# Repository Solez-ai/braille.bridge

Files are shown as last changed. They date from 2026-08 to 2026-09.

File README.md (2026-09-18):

# BrailleBridge

*A low-cost, bilingual (English + Bangla) digital Braille writing and classroom examination system.*

BrailleBridge lets blind and visually impaired students write independently — during classwork, assignments, and formal examinations — using familiar six-dot Braille chords. An ESP32 translates each chord in real time into readable English, Bangla, numbers, punctuation, and mathematical symbols, and delivers the result over two independent channels:

- **Bluetooth HID keyboard** — the output appears on the student's own phone, tablet, or computer, where a built-in screen reader reads it aloud.
- **USB Serial** — the same text arrives in the browser-based **Teacher Software**, giving sighted teachers readable output without ever learning Braille.

---

## Table of Contents

- [Why BrailleBridge](#why-braillebridge)
- [Key Features](#key-features)
- [Repository Structure](#repository-structure)
- [Hardware](#hardware)
  - [Bill of Materials](#bill-of-materials)
  - [GPIO Mapping](#gpio-mapping)
- [How It Works](#how-it-works)
  - [Braille Chording](#braille-chording)
  - [Language Switching](#language-switching)
  - [Shift Modifier](#shift-modifier)
- [Getting Started](#getting-started)
  - [Firmware (ESP32)](#firmware-esp32)
  - [Teacher Software](#teacher-software)
  - [Marketing Website](#marketing-website)
  - [3D-Printed Enclosure](#3d-printed-enclosure)
- [Serial Protocol](#serial-protocol)
- [Documentation](#documentation)
- [Roadmap](#roadmap)
- [License](#license)
- [Author](#author)

---

## Why BrailleBridge

In many classrooms and examination halls, a blind student cannot independently produce an answer sheet that a sighted teacher can immediately read. The common workaround — dictating every answer to a sighted writer — forces the student to:

- Speak answers aloud, losing privacy and confidentiality;
- Work at the writer's pace, losing control over speed;
- Risk transcription errors in technical terms, names, and Bangla phonetics;
- Hand over control of the final written record entirely.

Traditional embossed Braille solves the writing problem but is unreadable to most sighted teachers, and commercial digital Braille systems can cost hundreds or thousands of dollars.

BrailleBridge addresses the whole gap: the student writes through familiar Braille chords, the ESP32 translates instantly, and the teacher receives ordinary digital text — at a bill-of-materials cost of roughly **$12 per device**.

---

## Key Features

**Hardware device**

- Six mechanical Braille dot keys (Outemu Red, rated ~50M presses) plus dedicated Space and Shift keys
- ESP32 Dev Module with Bluetooth and USB Serial
- 180 ms chording window that reliably merges near-simultaneous key presses
- Two status LEDs (Red = English, Green = Bangla)
- Custom 3D-printed enclosure (Fusion 360 / FDM, top and bottom shells)
- Software language switching — no physical toggle switch required

**Translation**

- Full English alphabet (Grade 1 Braille, A–Z)
- Full Bangla dictionary following the **Bharati Braille** standard (vowels, consonants grouped by varga, vowel signs, halant, anusvara, visarga, candrabindu)
- Shift layer for numbers (1–0), punctuation, and math symbols (`+ - × ÷ =`)
- Shift + vowel produces Bangla dependent vowel signs (kar/matra)
- Unknown chords are rejected cleanly with LED blink feedback

**Teacher Software (browser-based)**

- Zero installation — runs in Chrome/Edge via the Web Serial API
- Multi-student roster with per-student COM ports and baud rates
- Live real-time feeds with language detection (`LANG:en` / `LANG:bn`)
- Exam mode: all students side by side in a monitoring grid
- Expandable per-student view with large serif text
- Timestamped exports (`[HH:MM:SS]` per character) as `.txt` files
- Persistent roster via `localStorage`
- Light/dark theme with `Ctrl+Shift+T` shortcut

---

## Repository Structure

```
.
├── braile/
│   └── braile.ino            # ESP32 firmware (Arduino / C++)
├── braille-display/
│   ├── index.html            # Teacher Software
│   ├── script.js
│   └── style.css
├── website/
│   ├── index.html            # Marketing / project website
│   ├── script.js
│   └── style.css
├── docs/
│   ├── braillebridge.tex     # Full research paper (XeLaTeX / LuaLaTeX)
│   └── ppt.pptx              # Presentation materials
├── models/
│   ├── TOP_SHELL.stl         # 3D-printable enclosure top
│   └── BOTTOM_SHELL.stl      # 3D-printable enclosure bottom
├── LICENSE                   # Apache License 2.0
└── README.md
```

---

## Hardware

### Bill of Materials

| Component | Qty | Cost (USD) |
| --- | --- | --- |
| ESP32 Dev Module | 1 | $5.00 |
| Outemu Red switch | 8 | $3.00 |
| Keycaps (3D-printed) | 8 | $1.00 |
| LED (3mm) + resistor | 2+2 | $0.30 |
| Perfboard | 1 | $0.80 |
| PLA filament (enclosure) | 30g | $1.20 |
| M3 screws, wire, solder  | — | $0.70 |
| **Total** | | **~$12.00**|

### GPIO Mapping

| Function | ESP32 GPIO | Notes |
| --- | --- | --- |
| Dot 1 | 14 | Top-left |
| Dot 2 | 12 | Middle-left |
| Dot 3 | 13 | Bottom-left |
| Dot 4 | 27 | Top-right |
| Dot 5 | 26 | Middle-right |
| Dot 6 | 25 | Bottom-right |
| Space | 33 | Dedicated space |
| Shift | 32 | Modifier |
| Red LED  | 18 | English mode |
| Green LED| 19 | Bangla mode |

All switches share a common ground bus. The firmware uses the ESP32's internal pull-up resistors: unpressed reads `HIGH`, pressed reads `LOW`.

---

## How It Works

### Braille Chording

A six-dot Braille cell is laid out as:

```
1 4
2 5
3 6
```

A character is produced by pressing one or more dots simultaneously. Each dot maps to a bit in a 6-bit value:

| Dot | Bit |
| --- | --- |
| 1 | 0 |
| 2 | 1 |
| 3 | 2 |
| 4 | 3 |
| 5 | 4 |
| 6 | 5 |

Because human fingers rarely land at the exact same microsecond, the firmware collects all keys pressed within a **180 ms window**, ORs them into a single chord value, and looks up the result in the active language dictionary.

Example: dots 1 + 4 → `0b001001` → **c** (English) / **চ** (Bangla).

### Language Switching

Hold **dots 4 + 5 + 6 for 500 ms** to toggle between English and Bangla. This exact chord is used by no standard letter or symbol, so accidental switching is practically impossible. The LEDs confirm the active language, and the firmware announces the change over Serial (`LANG:en` / `LANG:bn`) so the Teacher Software can update its indicator.

### Shift Modifier

Holding the physical Shift key while pressing a chord expands the vocabulary:

| Shift + chord | Output |
| --- | --- |
| Shift + A–J | Numbers 1–0 |
| Shift + math chord | `+`, `-`, `×`, `÷`, `=` |
| Shift + punctuation| `,` `;` `:` `.` |
| Shift + letter (EN)| Uppercase letter |
| Shift + vowel (BN) | Bangla vowel sign (kar/matra) |

### Shift Tap = Backspace

Tapping Shift alone (press + release **without** composing any chord) deletes the last typed character, like a normal keyboard's Backspace. All the hold-to-modify combos above work exactly as before — only a clean, unused tap fires the delete.

Guards so it never misfires:

- **Dots down during the tap** → modifier mode, no delete (checked both when dots are pressed and when Shift is released mid-chord).
- **Press shorter than 25 ms** → treated as bounce, ignored.
- **Hold longer than 1.5 s** → ignored, so pocketing the device can't wipe text.
- **100 ms cooldown** after a fired delete so contact bounce can't chain multiple backspaces.

The deletion goes out on both outputs: a real HID backspace over Bluetooth (works in any app on the connected computer/phone), and a `SYSTEM:BKSP` control line over Serial, which the Teacher Software already handles in student view, teacher mode, and exam mode.

### Shift Tap = Backspace

Tapping Shift alone (press + release **without** composing any chord) acts as a **Backspace** — it deletes the last typed character. Tap-and-chord combos behave exactly as before; only a clean, unused tap fires the delete. Deliberately long presses (>1.5 s) are ignored so the key can't misfire when pocketed.

The deletion is sent over both outputs: a real HID backspace to the connected device over Bluetooth, and a `SYSTEM:BKSP` control line over Serial, which the Teacher Software handles in student view, teacher mode, and exam mode.

---

## Getting Started

### Firmware (ESP32)

1. Install the [Arduino IDE](https://www.arduino.cc/en/software) and the [Arduino core for ESP32](https://github.com/espressif/arduino-esp32).
2. Open `braile/braile.ino` and upload it to an ESP32 Dev Module. *(No external libraries needed — the sketch uses only the ESP32 core's built-in BLE stack.)*
3. Pair the device (it appears as a Bluetooth keyboard named **BrailleBridge**) with the student's phone, tablet, or computer.
4. Open a text field, type Braille chords, and the translated text appears — while the same characters stream over USB Serial **and over BLE** to the Teacher Software.

> **BLE stream (Nordic UART Service):** alongside the HID keyboard service, the firmware now exposes the standard NUS (`6E400001-B5A3-F393-E0A9-E50E24DCCA9E`) — TX `…0002` notifies the exact serial stream (characters, `LANG:*`, `SYSTEM:BKSP`), RX `…0003` accepts `LANG:en` / `LANG:bn` commands back. This is the channel the future phone app (see [PHONE.md](PHONE.md)) consumes — no USB cable required.
>
> **Firmware v4 — BLE layer restored to the proven library:** after the v2/v3 hand-rolled GATT rewrites broke typing (malformed report-map Report-ID item) and then discoverability (advertising payload overflow), the BLE layer is back on the **T-vK BleKeyboard code that worked in v1** — vendored directly into the sketch folder as `braile/BBKeyboard.h/.cpp`, so no library install is needed. The **Nordic UART Service is grafted onto that proven stack** (own service UUID, doesn't touch HID/pairing/advertising), giving the phone app its data stream. Reflash once: phone keyboard mode, PC typing, and the app stream all come back together.

### Teacher Software

1. Open `braille-display/index.html` in **Chrome** or **Edge** (both support the Web Serial API).
2. Connect the ESP32 via USB; the browser will prompt you to select the serial port (115200 baud).
3. Add students, assign each to a COM port, and watch their typing appear live.
4. Use **Exam Mode** to monitor the whole class side by side, and **Export** to save timestamped logs per student.

No server, no database, and no installation required — the browser talks directly to the devices.

### Marketing Website

Open `website/index.html` in any browser, or deploy the folder to any static host (GitHub Pages, Netlify, etc.) for a public project site.

### 3D-Printed Enclosure

Print `models/TOP_SHELL.stl` and `models/BOTTOM_SHELL.stl` on an FDM printer (PLA, 0.2 mm layers). The MX-compatible switch cutouts let the eight Outemu switches snap in without glue or solder; the two shells fasten together with M3 screws.

---

## Serial Protocol

All translation happens on the ESP32, so the serial line carries only results at **115200 baud** (and the identical byte stream is mirrored over the BLE Nordic UART Service for the phone app):

| Message | Meaning |
| --- | --- |
| `LANG:en` | Language switched to English |
| `LANG:bn` | Language switched to Bangla |
| `Invalid` | Unrecognised chord rejected |
| `SYSTEM:BKSP` | Shift tap → delete last character |
| `<char>` | A translated character |

---

## Documentation

A full research paper is included at `docs/braillebridge.tex`. It covers the problem statement, hardware and firmware architecture, the English and Bharati Bangla dictionaries, the Teacher Software design, comparative analysis, affordability, and engineering innovations.

Compile it with **XeLaTeX or LuaLaTeX** (required for full Unicode/Bangla support):

```bash
xelatex braillebridge.tex
```

---

## Roadmap

- Verified full Bharati Braille implementation with experienced users
- Full mathematical Braille code (fractions, brackets, powers)
- Battery power with USB-C charging and battery reporting
- Audio confirmation and vibration feedback
- Secure examination mode with student identification
- PDF/DOCX export and cloud synchronisation
- Multi-school deployment and remote grading

---

## License

Licensed under the **Apache License, Version 2.0**. See [LICENSE](LICENSE) for the full text.

---

## Author

**Samin Yeasar**

- Email: [samin@mentormind.bd](mailto:samin@mentormind.bd)
- GitHub: [github.com/Solez-ai](https://github.com/Solez-ai)
- Web: [solez.html-5.me](https://solez.html-5.me)

*BrailleBridge does not replace Braille. It protects Braille as the student's natural writing method while removing the barrier between Braille input and teacher-readable output.*

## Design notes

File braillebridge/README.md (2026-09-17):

# BrailleBridge — Android App (Kotlin / Compose)

The mobile counterpart to the ESP32 BrailleBridge keyboard: receives the live
character + control-line stream over **Bluetooth Low Energy** (Nordic UART
Service) and mirrors every feature of the desktop/web teacher platform.

## ⚠️ How this app is built — READ FIRST

**Never build this app locally. No `gradlew`, no Android Studio builds on your
machine.** The single source of APKs is **GitHub Actions**:

1. Commit & push to `main` (any change — the workflow runs on every push).
2. Open the repo → **Actions** tab → *Build BrailleBridge APK*.
3. When the run finishes (green ✓), open it → **Artifacts** →
   **BrailleBridge-debug-apk** → download & unzip.
4. Copy `app-debug.apk` to your phone and install it
   (allow *Install unknown apps* for your file manager when prompted).

Need a build without a code change? **Actions → Build BrailleBridge APK →
Run workflow** (manual trigger).

The workflow (`.github/workflows/build-apk.yml`) uses JDK 17 + Gradle 9.3.1
and generates the debug keystore itself, so nothing secret is needed for
debug builds.

## Connecting to the BrailleBridge device

- **Keyboard mode (type into WhatsApp, any text field):** pair once in
  **Android Settings → Bluetooth** — the phone's own BLE HID stack handles it.
  No app involvement required.
- **App mode (live stream in this app):** open the app → the BLE service
  auto-connects to any device named *BrailleBridge* (or tap the Bluetooth
  icon in the top bar to scan manually).
- Both work at the same time: HID gives raw ASCII typing, the Nordic UART
  stream carries ASCII + Bangla + control lines (`LANG:*`, `SYSTEM:BKSP`).
- If characters ever stop appearing in the app: toggle the device's language
  switch (D4+D5+D6) — any `LANG:` line confirms the stream; if still silent,
  forget & re-pair the device in system settings, then reconnect.

## Feature parity

Student / Teacher / Exam / Exports tabs, teacher account (Samin Yeasar),
Google Translate with the full ~128-language catalogue, auto-formatted
export review with .txt download — all mirroring `braille-display/` and
`braille-desktop/`. Protocol and firmware details live in `PHONE.md`.

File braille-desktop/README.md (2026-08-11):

# BrailleBridge — Teacher Desktop

The BrailleBridge web app, wrapped in a desktop window with a **Python serial
relay**. Python owns every ESP32 COM port, so one device can be watched by the
Student View, the Teacher roster, and the Exam grid at the same time — no more
"Failed to open serial port" from two views fighting over one connection.

## Quick start

```bash
cd braille-desktop
pip install -r requirements.txt
python main.py
```

## What the Python side does

| Feature | Where |
|---|---|
| Owns COM ports (pyserial), one reader thread per port | `relay.py` |
| Streams every serial line/char into the embedded web UI | `relay.py` → `main.py` → JS |
| Auto-detects plug/unplug, pushes the port list to the UI | `relay.py` monitor loop |
| Auto-reconnects a dropped device when the port returns | `relay.py` monitor loop |
| Persists student ⇄ COM port assignments | `data/assignments.json` |
| Auto-saves each session as readable prose | `logs/` (on disconnect, Save Logs button, and app close) |

## Notes

- The window is Edge WebView2 (bundled with Windows 10/11). The browser
  version of `braille-display` still works unchanged — the app only switches
  to the relay transport when it detects `window.pywebview`.
- Google Fonts need an internet connection; offline the UI falls back to
  system serif fonts.
- Session logs land in `braille-desktop/logs/` as
  `{StudentName}_{timestamp}.log` with per-line timestamps.

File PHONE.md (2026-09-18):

# PHONE.md — Building BrailleBridge for Android (Kotlin, Bluetooth-Only)

> **Goal:** a phone app that looks and behaves **exactly** like the existing
> BrailleBridge teacher platform (`braille-display/` + `braille-desktop/`),
> except the transport is **Bluetooth Low Energy instead of USB serial** —
> with a **custom BLE proxy service that starts with the app**, so the phone
> takes full advantage of BLE from the first second.
>
> Every protocol rule, control line, boot-filter, chord table, timing constant
> and UI behavior below is copied **verbatim** from the current codebase, so
> the phone app is a drop-in replacement for the desktop one. Nothing about
> the student experience changes.

---

## 0. What must be identical (the rules)

| Rule | Value (do not change) | Source of truth |
|---|---|---|
| Device BLE name | `BrailleBridge` | `braile/braile.ino` — `BBKeyboard bleKeyboard("BrailleBridge")` (vendored T-vK library + NUS) |
| Serial baud (legacy/USB) | 115200 (also 9600/57600/38400 selectable) | `braille-display` UI + `braille-desktop/main.py` |
| Chord collection window | **180 ms** timeout, process on all-released OR timeout | `loop()` in `braile.ino` |
| Language toggle chord | Dots **4+5+6 held 500 ms** → toggle EN/BN, wait for release, then 50 ms settle | `loop()` |
| Shift behavior | Held = modifier; **tap alone (press+release, no chord) = BACKSPACE** | `braile.ino` shift state machine |
| Shift tap guards | min 25 ms, max 1500 ms, 100 ms cooldown, dots-held veto | `braile.ino` |
| Space | Immediate char + 200 ms debounce, block until released | `loop()` |
| Control lines | `SYSTEM:…`, `LANG:en`, `LANG:bn`, `Invalid`, `SHIFT` — never rendered as text | `relay.py CONTROL_PREFIXES` |
| Backspace control line | `SYSTEM:BKSP` on its own line | `sendBackspace()` |
| Language lines | `LANG:en` / `LANG:bn` (exactly, lowercase suffix) | `loop()` |
| Boot preamble filter | Drop `ets `, `rst:0x`, `boot:0x`, `configSPIWP`, `clk_drv:`, `q_drv:`, `d_drv:`, `cs0_drv:`, `hd_drv:`, `wp_drv:`, `mode:DIO`, `load:0x`, `entry 0x`; stateful: after `ets ` suppress until `entry 0x` or a `SYSTEM:` line | `relay.py BOOT_PREFIXES` + `makeBootFilter()` in `script.js` |
| Chord dictionaries | Bharati Braille tables — EN a–z, BN full varnmala, কার shift map, numbers 1–0 on Shift+A–J, math/punct symbols | `brailleDict[]`, `numberChords[]`, `shiftSymbols[]`, `banglaShiftMap[]` |
| Unknown chord | **Silently ignored** (no output, no error) | `processChord()` |
| BLE ASCII rule | Only ASCII goes to BLE HID; Bangla (multi-byte UTF-8) is serial/transport only — pushing it to HID wedges the ESP32 | `sendChar()` comment in `braile.ino` |

---

## 1. Transport: what changes on the phone

The desktop app reads the ESP32 over **USB COM port via pyserial**. On Android
there is no COM port — the same byte stream arrives over **BLE GATT
notifications**. The protocol layer above it must not change.

### 1.1 The ESP32 side — ✅ IMPLEMENTED (`braile/braile.ino`)

The firmware runs the **T-vK BleKeyboard code that worked in v1 — vendored
into the sketch folder** as `braile/BBKeyboard.h/.cpp` (class renamed
`BBKeyboard`), with the **Nordic UART Service grafted on** as a second
service. No library install needed. This is the proven pairing/typing stack
(keyboard appearance 0x03C1, SC+MITM bonding, T-vK report map and
advertising shape) plus one added data channel:

1. **HID over GATT (0x1812):** byte-for-byte the library build — paired
   hosts see a keyboard named **BrailleBridge** and receive ASCII typing
   exactly as v1 did on phones and PCs.
2. **Nordic UART Service (the proxy channel):** the *raw character +
   control-line stream* that goes to Serial is mirrored over BLE:

```cpp
// implemented — BBKeyboard.h (NUS ADDITION section)
#define NUS_SERVICE_UUID "6E400001-B5A3-F393-E0A9-E50E24DCCA9E"
#define NUS_TX_UUID      "6E400002-…"   // notify: chars, LANG:*, SYSTEM:BKSP
#define NUS_RX_UUID      "6E400003-…"   // write: phone can send LANG:en/LANG:bn
```

`sendChar()` writes to Serial **and** notifies NUS (MTU-chunked);
`streamLine()` does the same with `\n` appended. Non-subscribed centrals are
skipped automatically by the stack's CCCD handling.

**MTU:** the peripheral sets MTU 247. On the Android side call
`requestMtu(247)` right after `onDescriptorWrite` succeeds and **buffer
partial notifications** (see §2.3).

### 1.2 The BLE proxy service (starts with the app)

A foreground `Service` that owns *all* Bluetooth work, starts on app launch,
survives Activity recreation, and re-publishes itself:

```kotlin
class BleProxyService : Service() {
    // One connection per student device, mirroring relay.py's _conns map
    private val connections = ConcurrentHashMap<String, BleDeviceConn>()
    private val assignments = ... // persisted name->MAC, like data/assignments.json

    override fun onStartCommand(...) = START_STICKY
}
```

Responsibilities (each one maps 1:1 to `relay.py`):

| relay.py | BleProxyService |
|---|---|
| `_monitor_loop()` re-scan every 2 s | `ScanCallback` loop with `ScanSettings.SCAN_MODE_LOW_POWER` between windows; auto-connect by MAC when a **bonded/known** `BrailleBridge` device appears |
| `open_port(name, baud)` | `connectGatt(context, false, callback, TRANSPORT_LE)` + discovery + enable notifications |
| `close_port(name)` | `gatt.disconnect(); gatt.close()`, keep the conn object for reconnect |
| auto-reconnect on drop | `onConnectionStateChange → DISCONNECTED` ⇒ exponential backoff reconnect (1s, 2s, 4s… cap 10s), emit `reconnect` event when back |
| `_read_loop` incremental UTF-8 decoder | accumulate `ByteArray` notifications; decode with `CharsetDecoder` in `CodingErrorAction.REPLACE` — a Bangla char split across two notifications must not become garbage |
| `CONTROL_PREFIXES` routing | identical line splitter, §2.2 |
| logs/ + data/assignments.json | Room DB + DataStore, same JSON shape |

**Foreground requirement:** `FOREGROUND_SERVICE` + `BLUETOOTH_CONNECT` +
`ACCESS_FINE_LOCATION` (scan) permissions; show a persistent
"BrailleBridge BLE bridge active — N devices" notification. Start the service
in `Application.onCreate()` so BLE is live before the first frame renders —
that is the "proxy comes up as the app starts" rule.

### 1.3 Connection UX parity

- Student view "Connect" button lists nearby `BrailleBridge` devices
  (name-filtered scan), shows RSSI; remembers last device and auto-connects.
- Teacher roster Add-Student form: same three rows (Name / **Bluetooth**
  / "baud" row becomes **Device picker**) — keep the baud select in the UI for
  parity but disable it when connType = bluetooth (baud is a USB concept).
- Status dot + `Connected/Disconnected` label behave identically
  (`updateSerialUI` equivalent).

---

## 2. Protocol layer (port these exactly)

### 2.1 Line model

`makeSerialFeed(onLine, onChars)` in `script.js` is the canonical behavior:

```
buffer += chunk
while newline in buffer: emit trimmed line to onLine
if trailing partial: emit to onChars   // chars arrive without \n
```

The Kotlin port (`LineFeed`) must do the same split, then classify:

- starts with `SYSTEM:` → control (handle `SYSTEM:BKSP`, ignore rest)
- equals `LANG:en` / `LANG:bn` → switch language state, update indicators
- equals `Invalid` or `SHIFT` → ignore (never render)
- else → character data

### 2.2 Boot suppression (stateful port)

```
var suppress = false
fun dropLine(line): Boolean {
  if (line.startsWith("ets ")) { suppress = true; return true }
  if (suppress) {
    if (line.startsWith("entry 0x") || line.startsWith("SYSTEM:")) suppress = false
    else return true
  }
  return BOOT_PREFIXES.any(line::startsWith)
}
```
Partial chunks (`ets ` without newline) set suppress exactly like
`relay.py _read_loop`.

### 2.3 MTU-safe reassembly

BLE notifications arrive in ≤ (MTU-3) byte chunks. Reassemble at the byte
level, decode incrementally (surrogate-safe), then feed `LineFeed`. This
mirrors `codecs.getincrementaldecoder('utf-8')(errors='replace')`.

---

## 3. Dictionaries (port these tables byte-for-byte)

Copy from `braille-display/script.js` (identical to the firmware tables):

- `brailleDict` — 52 entries: shared EN/BN chords + Bangla-only cells +
  convenience cells (ি, ূ, duplicate স). Keep **`f`, `w` having `bangla: null`**
  and the `null` entries exactly — the "chord exists but not in this language"
  rule returns null (silently ignored).
- `numberChords` / `numberMap` — Shift+A–J → 1–0.
- `shiftSymbols` — math first (`+ − × ÷ =` — note `×` at 0b100110 shares chord
  with `,` handling order), then `, ; : .` (order matters: 0b010110 `+` before
  0b100110 `×`).
- `banglaShiftMap` — vowel → কার, with অ (0b000001) mapping to **null**
  → falls through to normal output (do not "fix" this).
- Translation priority when Shift held: numbers → math/punct → uppercase EN →
  কার BN → fallback normal BN char → else ignore.

## 4. Feature parity checklist (all of these exist today; all must exist on phone)

### Student view
- 6-dot clickable Braille cell with dot order layout (1-4 / 2-5 / 3-6 columns),
  pressed-dot animation + pulse, chord binary + dots readout, live mapping line
- English/বাংলা + Shift indicators (LED semantics: EN=red LED, BN=green LED)
- Live output stream with per-char spans, Bangla font stack
  (`Noto Serif Bengali → Nirmala UI → Vrinda`), blinking cursor, auto-scroll
- Recent characters strip (80-char rolling window)
- Clear button, keyboard shortcuts (1–6 dots, Space, Enter commit, Esc clear,
  L language, S shift) — on phone these become physical-keyboard support only
- **Backspace tap** reflected live (device Shift tap removes last char)
- Send-to-Teacher mirror (`mirrorStudentId` semantics: one connection, two views)

### Teacher view
- Roster with avatars (initials + 8-color palette `#5a8ae0 #d45a5a #5ab85a
  #c49a4a #8a6ad4 #4ac8b8 #e08a5a #5ab8b8`), online/offline dot, connect button
- Feed grid cards: header (avatar/name/conn badge/baud/status), body
  (live stream), chord bar (6 mini dots + `0b…` + char count)
- Per-card actions: Preview(prose) · Expand · Test(simulate `hello বাংলা`
  typing at 200 ms/char) · Export · Clear · Remove
- Toolbar: student count, total chars, Save Logs, **Export All**, Clear All
- Backspace handling per student (`handleStudentBackspace` pops `{char,time}`)
- Periodic 500 ms failsafe refresh of all feeds

### Exam view
- Same cards, no per-card actions, toolbar shows student/char counts,
  Export button — feeds stay live during exams, chars still timestamped

### Modals
- **Preview modal:** readable prose — group chars into words/lines, ≤52 chars
  per line after the `[HH:MM:SS]` prefix, line timestamp = first char typed;
  Export + Save-to-Exports buttons; footer "N character(s) — M line(s)"
- **Expand modal:** full live view of one student, scroll-to-bottom button,
  Ctrl+Enter clear, preview hand-off
- **Send modal:** mirror flow (name + conn + baud), duplicate-mirror guard

### Everything new that must also exist on phone (§6–§8)
- Teacher account UI — **Samin Yeasar** (identical to §7)
- Google Translate integration (identical to §6)
- Exports tab with saved exports, review screen, auto-formatter (§8)

---

## 5. Android architecture

```
/app
  /ble            BleProxyService, BleDeviceConn, GattCallbacks, LineFeed,
                  BootFilter, Utf8Reassembler      ← §1–2
  /protocol       BrailleDict.kt, Translate.kt (tables + lookup priority) ← §3
  /data           StudentRepo (Room: students, chars{char,time}, exports),
                  SettingsStore (theme, assignments JSON)
  /ui
    /student      StudentScreen (cell, output, translate bar)
    /teacher      RosterScreen, FeedGrid, StudentCard
    /exam         ExamScreen
    /exports      ExportsScreen (list) + ReviewScreen (formatted doc)
    /account      AccountSheet (Samin Yeasar profile)
    /theme        Theme.kt — port BOTH light & dark palettes
```

- **Jetpack Compose**, MVVM, one `SharedViewModel` per mode mirroring the
  global-state style of `script.js` (`students[]`, `totalCharsAllStudents`,
  `isBangla`, `shiftActive`).
- **Compose Multiplatform note:** not needed — single Android target.
- ViewModels survive rotation; the BLE service is the source of truth and
  pushes via `StateFlow` — exactly how `relay.py` pushes into the webview.

### Theme ports

Dark (default) from `style.css :root`:
`--bg-dark #0f111a · --bg-panel #161822 · --bg-card #1c1f2e ·
--bg-surface #242738 · --bg-hover #2d3044 · --text #e8e6e0 / #a8a4a0 / #6a6a7a ·
--gold #c49a4a · --gold-light #dbb86a · --gold-dark #a07828 ·
--accent-red #d45a5a · --accent-green #5ab85a · --accent-blue #5a8ae0 ·
--accent-purple #8a6ad4 · --accent-teal #4ac8b8 ·
--radius 8/14/20 · Inter + Playfair Display + Noto Serif Bengali`

Light: `#f4f3f0 / #ffffff / #faf9f6 / #efede8 / #e6e3dc`, ink `#1a1a2e`,
same accents. Ctrl+Shift+T theme toggle → app setting + top-bar icon.
The dot buttons use `linear-gradient(145deg …)` with the `0 5px 0` hard
drop-shadow — replicate with two-layer shadow in Compose.

---

## 6. Google Translate (same behavior on both platforms)

Reference implementation: `braille-display/shared.js → BBTranslate`.

- **FULL LANGUAGE CATALOGUE (updated rule):** every language Google Translate
  supports (~128 codes) must be selectable — port the `LANGUAGES` table from
  `braille-display/shared.js` verbatim into `Translate.kt` as
  `data class BBLanguage(val code: String, val name: String, val cc: String)`.
  The picker is a native dropdown (Material3 `ExposedDropdownMenuBox` or
  `Spinner`) listing "flag + English name", defaulting to English (`en`).
- Endpoint: `https://translate.googleapis.com/translate_a/single?client=gtx&sl=auto&tl=<target>&dt=t&q=<text>`
  (parse `data[0][i][0]` segments), fallback
  `/language/translate/v2` v2 shape. **Cache** every (source,target,text) pair.
- Source is ALWAYS `auto`; Google returns the detected code — display it:
  `"(Bangla → French)"` style, via a `name(code)` lookup over the same table.
  Local fallback (`detectLanguage()`): Bengali range `[\u0980-\u09FF]` →
  display "Bangla" when Google's detection is unavailable.
- **Live bar (student view):** appears under Live Output the moment the stream
  has content (MutationObserver on web / snapshot flow on Android), language
  dropdown + "Translate" button → shows result inline with the
  `(detected → target)` caption. Choosing a new language and pressing
  Translate again re-translates from the ORIGINAL text (keep the original
  stream text separately from the displayed translation).
- **Review translate:** see §8.3 (translate the formatted document into ANY
  chosen catalogue language, original preserved, picker defaults to last use).
- Android: `OkHttp` + `kotlinx.serialization`; do the request off-main;
  same cache in memory (and optionally DiskLru).

## 7. Teacher Account UI — Samin Yeasar (both platforms, look legit)

Reference: `shared.js ensureModals()` + `shared.css`. Two parts:

1. **Header chip** (always visible, both modes): gold-gradient avatar `SY`,
   name **Samin Yeasar**, role *Teacher*, chevron. On the website the same
   chip lives in the nav (`siteAccountChip`).
2. **Profile modal** (opens on tap; Esc/overlay click closes):

```
┌────────────────────────────────────┐
│ ░ patterned navy/gold banner ░  ✕  │
│  (SY)  ← 78px gold avatar, overlap │
│                                    │
│  Samin Yeasar  ✓(teal verified)    │
│  Teacher · Braille Literacy        │
│  [🪪 BB-T-0001][🛡 Verified][🔒 Local profile] │
│  ┌───────┬────────┬───────────┐    │
│  │   3   │   12   │   1,204   │    │
│  │Students│Exports│Characters │    │   ← live from app state
│  └───────┴────────┴───────────┘    │
│  ✉ samin.yeasar@braillebridge.edu  │
│  🏫 Special Education — BrailleBridge Academy │
│  🌐 English · বাংলা · Google Translate enabled  │
│  📅 Member since 2026 · Device owner│
│  ( Sign out )  ( Close )           │
└────────────────────────────────────┘
```

Stats row is **live**: students = roster size, exports = exports count,
characters = `totalCharsAllStudents` (website shows `—` when no roster).
Sign out shows the demo toast: *"Signed out of this session (demo account
stays active)."*

## 8. The Exports section (both platforms)

### 8.1 Trigger points
- **"Export All"** (teacher toolbar), **"Export"** (exam toolbar),
  **Export** (per-student card & preview modal) → the .txt download happens
  exactly as today, **and** the export is saved into the Exports library with
  a toast *"…saved to Exports"*.
- Website demo: new **Export** toggle next to Clear saves the demo stream
  (`source: demo`).
- Preview modal gains **"Save to Exports"** (save without downloading).

### 8.2 The Exports tab
- Desktop app: new **Exports** button in the mode toggle (Student/Teacher/
  Exam/**Exports**) → opens the Exports modal (does not switch away from the
  current view). Phone: bottom-nav destination.
- List cards: icon (user/class/flask), title, timestamp, mode, char count,
  conn info, block count, actions: **Review** · **.txt** · **Delete**.
  Clear-all with confirm. Storage cap 100 (FIFO). Web storage:
  `localStorage['bb-exports-v1']` / `['bb-site-exports-v1']`;
  Android: Room table `exports(id, title, mode, source, charsCount,
  blocksJson, created)`.

### 8.3 Review screen (the "better way to review")
- Formatted document view rendered by the **auto-formatter** (§8.4):
  real title/heading/paragraph/list typography, gold rule under titles,
  per-block timestamps visible in Raw mode.
- Toolbar: **Back · Translate → <language picker> · Raw · Download .txt**
  - Translate converts the whole document into the picked language (full
    catalogue); toggling between original/translated preserves both;
    download exports whatever is currently shown.
  - Raw = monospace timestamped lines.
- Footer: title · char count · formatted block count.

### 8.4 Auto-formatter rules (port `BBAutoFormat` exactly)
1. Chars → lines: space = word boundary (collapse runs), `\n/\r` = line break;
   each line keeps the **timestamp of its first character**.
2. Headings by keyword, EN + BN:
   `chapter/অধ্যায়`→H1 · `section/অনুচ্ছেদ`→H2 · `lesson/পাঠ`→H3 ·
   `exercise/অনুশীলন/question/প্রশ্ন`→H4.
3. Bullets: line starts `- * • · →`; numbered: `\d+[.)]`.
4. Everything else accumulates into a paragraph (lines joined with spaces).
5. Punctuation fixer: no space **before** `.,;:!?।`, exactly one space
   **after** (not between digits/decimal), collapse multi-spaces, `....`→`...`.
6. Title: first paragraph block if ≤60 chars, ≤6 words, no terminal
   punctuation.
7. Output blocks `{type: title|heading|para|bullet|numbered, text, time,
   level}` — same JSON stored in each export; `.txt` serializer: titles
   UPPERCASE, blank lines around headings/paras, `• ` bullets, `N.`
   numbering (counter resets at headings/paras/titles).

---

## 9. Milestones

1. **M1 Transport:** firmware NUS addition + Android BLE service that connects
   and streams the same byte stream the desktop sees (verify with the
   `SYSTEM:` banner, `LANG:` lines, boot-filter working).
2. **M2 Student parity:** dot cell, output stream, indicators, backspace tap,
   keyboard parity — golden test: type the alphabet in EN, vowels+কার in BN,
   numbers/math/punct with Shift, tap-delete, language toggle; byte-compare
   the resulting stream against desktop.
3. **M3 Teacher/Exam:** roster, feeds, modals, timestamps, backspace sync.
4. **M4 Shared features:** account UI, translate, exports + auto-formatter.
5. **M5 Hardening:** reconnection storms, MTU fragmentation fuzz (split
   Bangla chars across notifications), 2+ devices concurrently, battery
   (scan duty cycling).

## 10. Testing checklist (run on both platforms, expect identical output)

- [ ] Chord → char for all 26 EN, all BN cells, all কার, digits, `+ − × ÷ = , ; : .`
- [ ] Shift priority conflicts (e.g. 0b010110 = `+` and also ফ-chord family)
- [ ] D4+5+6 short press does NOT toggle; ≥500 ms does; works while Shift held
- [ ] Shift tap = 1 backspace; Shift+chord = modifier; Shift+Space = space, no delete
- [ ] Bounce: 15 ms Shift flicker → nothing; release bounce → 1 delete
- [ ] `SYSTEM:BKSP` removes last char in student view, teacher feed, exam feed, mirror
- [ ] Boot garbage never appears (power-cycle the ESP32 mid-session)
- [ ] Bangla split across BLE packets renders correctly
- [ ] Export saved → appears in Exports → review shows title/headings/lists →
      translate to any catalogue language → download matches on-screen text
- [ ] Account modal shows live stats; website shows `—` stats without roster
- [ ] Theme toggle persists; both palettes render all new UI correctly

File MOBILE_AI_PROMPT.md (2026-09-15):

# MOBILE_AI_PROMPT.md

> **How to use this file:** open your AI coding tool (Cursor, Claude Code, GitHub Copilot Workspace, Codebuff, Windsurf, …), start a session inside this repository, and paste everything below the horizontal rule as your prompt. The prompt tells the agent which files in this repo are the source of truth and what "done" means. Do not edit this file when requirements change — edit `PHONE.md` (the spec) and the reference implementations it points to; this prompt just routes the agent there.

---

## THE PROMPT (copy from here down)

You are building **BrailleBridge Mobile**, the official Android (Kotlin) companion app for the BrailleBridge project — a braille chording keyboard (ESP32 hardware) with a teacher platform. The app must look and behave **exactly** like the existing teacher platform, connect **only via Bluetooth LE**, and speak the **exact same protocol** as the existing desktop/web software. This is a parity port, not a redesign.

### 0. Read these repository files FIRST — they are the source of truth

| File | Why |
|---|---|
| `PHONE.md` | **The authoritative build spec.** Architecture, package layout, theme values, milestone plan, acceptance checklist. Follow it section by section. |
| `README.md` | Serial/BLE protocol reference (§ Protocol), hardware overview, Shift-tap-backspace behavior. |
| `braile/braile.ino` | The firmware. Confirms the Nordic UART Service (NUS) the app consumes: TX `6E400002-B5A3-F393-E0A9-E50E24DCCA9E`, RX `6E400003-…`, MTU 247, device name **"BrailleBridge"**. |
| `braille-desktop/relay.py` | The desktop relay — your `BleProxyService` is a 1:1 port of its line assembly, UTF-8 reassembly, boot-garbage filter, and control-line dispatch. |
| `braille-display/index.html`, `script.js`, `style.css` | The web teacher platform you must replicate in UI and behavior (modes: Student / Teacher / Exam, live output, roster, exam grid). |
| `braille-display/shared.js`, `shared.css` | The shared engine you must port: `BBTranslate` (full 128-language Google Translate catalogue — copy the `LANGUAGES` table verbatim), `BBAutoFormat` (title/heading/paragraph/list formatter — port every regex), `BBExports` (localStorage store → Room/DataStore on Android), `BBAccount` (teacher account UI). |
| `website/index.html`, `script.js` | Reference for the account chip in the nav and the demo's translate/export wiring. |

### 1. Mission and hard constraints

1. **Bluetooth only.** No USB serial, no cloud backend, no accounts server. The ESP32 streams over BLE NUS; the app connects directly to it.
2. **BLE proxy service:** a foreground `BleProxyService` starts when the app launches (not when the user opens a screen). It scans, auto-reconnects, reassembles lines/UTF-8, filters boot garbage, and broadcasts every complete line to the UI layer — exactly mirroring `relay.py`. The rest of the app never talks to Bluetooth directly.
3. **Protocol parity is non-negotiable.** Every rule below is already implemented on the device and desktop; do not reinterpret, rename, or "improve" any of it:
   - Device advertises/connects as **"BrailleBridge"**; prefer auto-connect (`createBond`-less reconnection) and request **MTU 247**.
   - Subscribe to NUS TX (`6E400002…`) notifications; write language commands to NUS RX (`6E400003…`).
   - Lines end with `\n`. Data lines are plain characters (a character per chord result); control lines start with a prefix:
     - `LANG:en` / `LANG:bn` — device language toggled (dispatch to UI, also update your UI state)
     - `SYSTEM:BKSP` — delete the last character (student output, teacher feed, exam feed, mirror — everywhere)
   - **UTF-8 reassembly:** a multi-byte Bangla character (or any non-ASCII) may split across BLE packets. Buffer incomplete sequences exactly like `relay.py` does.
   - **Boot filter:** for ~1.5 s after connect, drop ESP32 boot/log lines (`rst:`, `load:`, `entry`, `boot:`, non-UTF-8 noise) so garbage never reaches the display.
4. **Feature parity checklist** (all must exist):
   - **Student view** — live output stream (character-by-character append, backspace removes), language LEDs EN/বাংলা, dot keypad simulator, Shift toggle, clear button, live translate bar.
   - **Teacher view** — live feed, per-student roster (add/remove/persist), student switching, per-student export.
   - **Exam mode** — locked-down feed, copy protection, exam stats, per-student exam export.
   - **Exports tab** — every export auto-saves to a persisted library; review screen renders the **auto-formatted** document (real title/heading/paragraph/list typography, gold rule under titles), Raw mode (timestamped lines), Translate (any catalogue language), Download `.txt` (via SAF), delete/clear.
   - **Auto-formatter** — port `BBAutoFormat` from `shared.js` rule-for-rule: title detection (short line, few words, no terminal punctuation), heading keywords (`chapter`, `অধ্যায়`, `section`, `অনুচ্ছেদ`, `lesson`, `পাঠ`, …), bullets (`*`, `-`, `•`), numbered lists, paragraph joins, space/punctuation normalization.
   - **Google Translate** — full catalogue (**all ~128 languages** Google Translate supports; port the `LANGUAGES` table from `shared.js` verbatim), source `auto`, display `(detected → target)` caption, cache results, native language dropdown defaulting to English. Present in: student live bar + every export review screen.
   - **Teacher account UI** — chip (initials avatar + name) opening a profile modal for **Samin Yeasar**, role **Teacher — BrailleBridge**, ID **BB-T-0001**, verified badge, live stats (students / exports / characters), contact rows, sign-out button (cosmetic). It must look legitimate — polish matters.
   - **Theme** — port the exact navy/gold palette and IBM Plex fonts from `braille-display/style.css` + `shared.css`; support light and dark (the platform supports both).
5. **Tech stack (from PHONE.md §4):** Kotlin, Jetpack Compose, Material 3, MVVM (`ui/`, `data/`, `ble/`, `protocol/`), `AndroidX Bluetooth LE` APIs, `OkHttp` + `kotlinx.serialization` for translate, Room or DataStore for exports/roster, foreground service with `BLUETOOTH_CONNECT` / `POST_NOTIFICATIONS` runtime permissions (API 31+).
6. **Quality bar:** no `!!`, all strings in `strings.xml`, min SDK 26, target latest stable. The app must survive: device power-cycled mid-session (boot filter + auto-reconnect), Bangla split across packets, BLE drop/reconnect without app restart, and rapid backspace taps.

### 2. Definition of done

Run through the acceptance checklist at the end of `PHONE.md` — every box must pass, including:
- Character typed on the device appears in the app within ~100 ms; `SYSTEM:BKSP` deletes it in every view.
- `LANG:en`/`LANG:bn` lines update the app's language state.
- Translate works **to any of the ~128 catalogue languages** and the `(detected → target)` caption shows the right names.
- Export → appears in Exports → review shows formatted document → translate → download matches the on-screen text.
- Account modal shows live stats.
- All UI matches the navy/gold platform theme in both light and dark.

If anything in this prompt conflicts with `PHONE.md` or the reference code, **the reference code wins** — port it, don't redesign it.

*(end of prompt)*

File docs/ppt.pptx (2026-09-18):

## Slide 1

Braille Bridge

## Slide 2

Braille Bridge

A Low-Cost Bilingual Braille Writing System

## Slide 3

Braille Bridge

Slate & Stylus

A Low-Cost Bilingual Braille Writing System

Minor Writing
Too Manual
Too Complex
Risk of Lost Parts
Not Convenient

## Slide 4

A Low-Cost Bilingual Braille Writing System

Braille Bridge

Perkins Braille

Slate & Stylus

Minor Writing
Too Manual
Too Complex
Risk of Lost Parts
Not Convenient

Minor Writing
Too Manual
Too Complex
Risk of Lost Parts
Not Convenient

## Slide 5

A Low-Cost Bilingual Braille Writing System

Slate & Stylus

Braille Bridge

Custom 3d
Printed Shell
with Ergonomic
Design Made for
Flexibility
& Scalability

PCB Support

- Requires Braille paper to produce its normal output.
- Produces tactile Braille rather than directly providing digital text in the standard model.
- Teachers who do not know Braille cannot directly read the embossed output.

Perkins Braille

Too Bulky
Very Heavy
Finger Fatigue
Loud Noise
700-800 USD!

Converts Braille input into readable digital English and Bangla.
Real-time Teacher Software allows teachers to see student output without knowing Braille.
No paper required for digital classroom work.
Bluetooth connectivity allows it to work with computers, phones, and other compatible devices.

x8 Tactile Switches

6 Keys to Type + Shift and Space Key

Minor Writing
Too Manual
Too Complex
Risk of Lost Parts
Not Convenient

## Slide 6

A Low-Cost Bilingual Braille Writing System

Slate & Stylus

Braille Bridge

Custom 3d
Printed Shell
with Ergonomic
Design Made for
Flexibility
& Scalability

PCB Support

PCB Support

Perkins Braille

- Requires Braille paper to produce its normal output.
- Produces tactile Braille rather than directly providing digital text in the standard model.
- Teachers who do not know Braille cannot directly read the embossed output.

The Solution

Converts Braille input into readable digital English and Bangla.
Real-time Teacher Software allows teachers to see student output without knowing Braille.
No paper required for digital classroom work.
Bluetooth connectivity allows it to work with computers, phones, and other compatible devices.

x8 Tactile Switches

6 Keys to Type + Shift and Space Key

Too Bulky
Very Heavy
Finger Fatigue
Loud Noise
700-800 USD!

Minor Writing
Too Manual
Too Complex
Risk of Lost Parts
Not Convenient

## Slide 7

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
Braille Bridge

Custom 3d
Printed Shell
with Ergonomic
Design Made for
Flexibility
& Scalability

x8 Tactile Switches

6 Keys to Type + Shift and Space Key

Perkins Braille

Too Bulky
Very Heavy
Finger Fatigue
Loud Noise
700-800 USD!

PCB Support

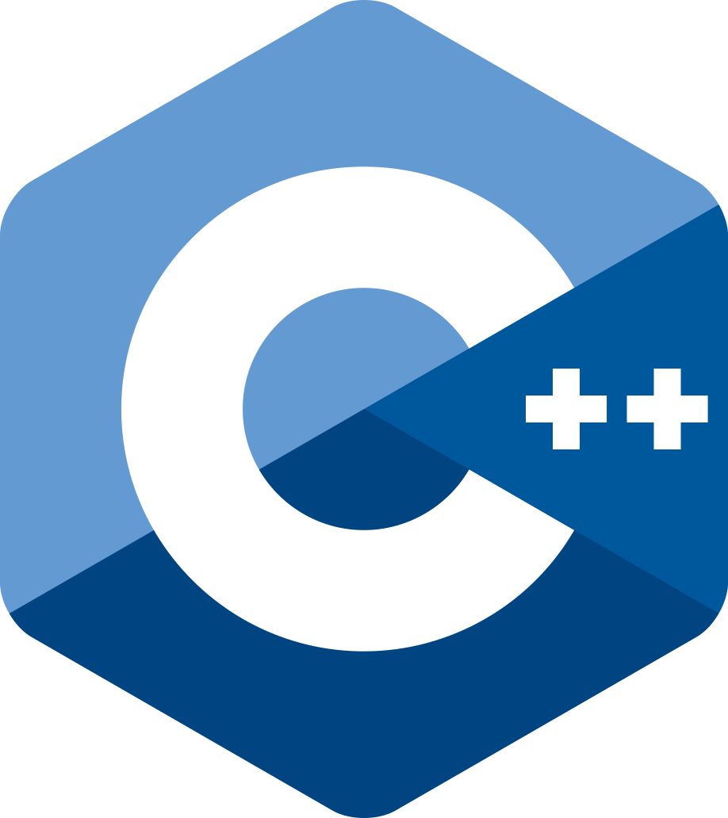
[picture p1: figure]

ESP-32

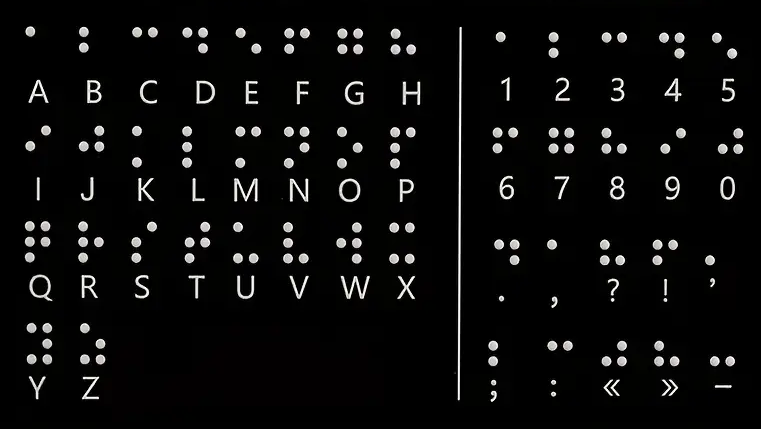
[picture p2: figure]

S
Y
S
T
E
M

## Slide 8

A Purpose-Built Teacher Software

Braille Bridge

What’s Chording?

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
Custom 3d
Printed Shell
with Ergonomic
Design Made for
Flexibility
& Scalability

Chording is a typing method where you press multiple keys at the same time to produce one character or command. Instead of pressing one key for each letter, different combinations of keys represent different characters. In BrailleBridge, the six keys represent the six dots of a Braille cell, so pressing dot 1 produces A, while pressing dots 1+2 together produces B, and dots 1+4 produces C. This lets a blind user type using the same dot combinations they already use in Braille, rather than learning a completely different keyboard layout.

x8 Tactile Switches

6 Keys to Type + Shift and Space Key

PCB Support

ESP-32

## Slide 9

Braille Bridge

A Purpose-Built Teacher Software

What’s Chording?

Chording is a typing method where you press multiple keys at the same time to produce one character or command. Instead of pressing one key for each letter, different combinations of keys represent different characters. In BrailleBridge, the six keys represent the six dots of a Braille cell, so pressing dot 1 produces A, while pressing dots 1+2 together produces B, and dots 1+4 produces C. This lets a blind user type using the same dot combinations they already use in Braille, rather than learning a completely different keyboard layout.

Custom 3d
Printed Shell
with Ergonomic
Design Made for
Flexibility
& Scalability

x8 Tactile Switches

6 Keys to Type + Shift and Space Key

PCB Support

ESP-32

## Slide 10

What’s Chording?

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
Braille Bridge

A Purpose-Built Teacher Software

BrailleBridge does not replace Braille. It protects Braille as the student's natural writing method while removing the barrier between Braille input and teacher-readable output.

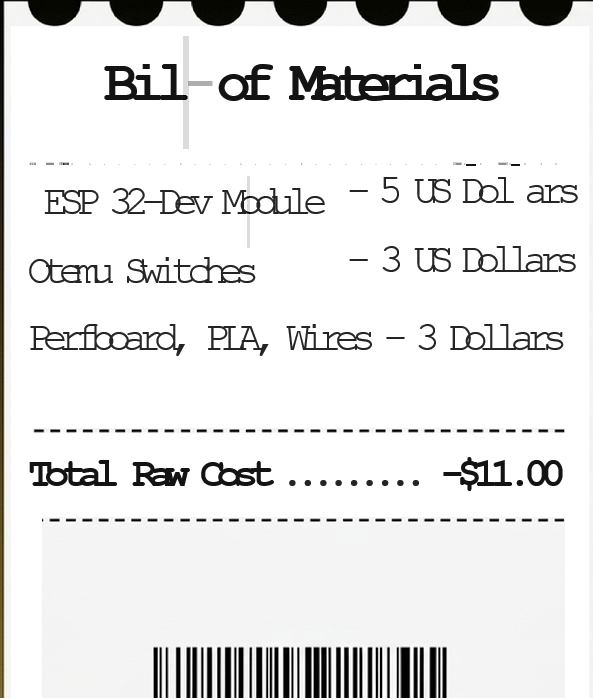
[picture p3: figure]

S
Y
S
T
E
M

Chording is a typing method where you press multiple keys at the same time to produce one character or command. Instead of pressing one key for each letter, different combinations of keys represent different characters. In BrailleBridge, the six keys represent the six dots of a Braille cell, so pressing dot 1 produces A, while pressing dots 1+2 together produces B, and dots 1+4 produces C. This lets a blind user type using the same dot combinations they already use in Braille, rather than learning a completely different keyboard layout.

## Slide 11

Braille Bridge

A Purpose-Built Teacher Software

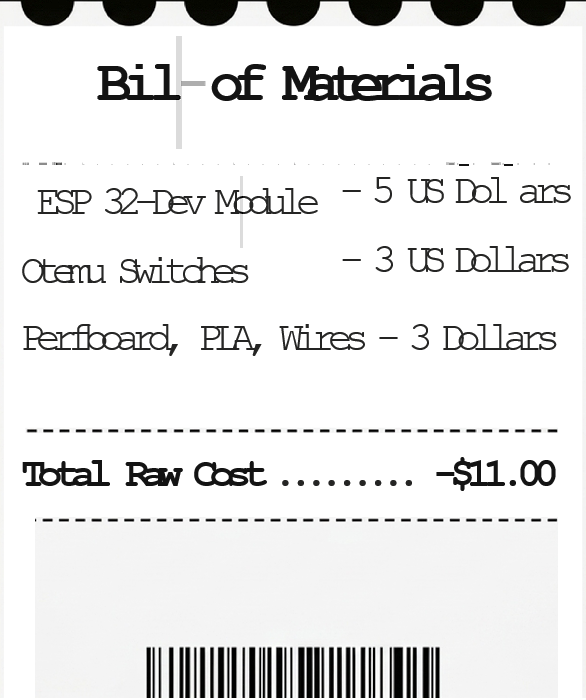
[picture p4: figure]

BrailleBridge does not replace Braille. It protects Braille as the student's natural writing method while removing the barrier between Braille input and teacher-readable output.

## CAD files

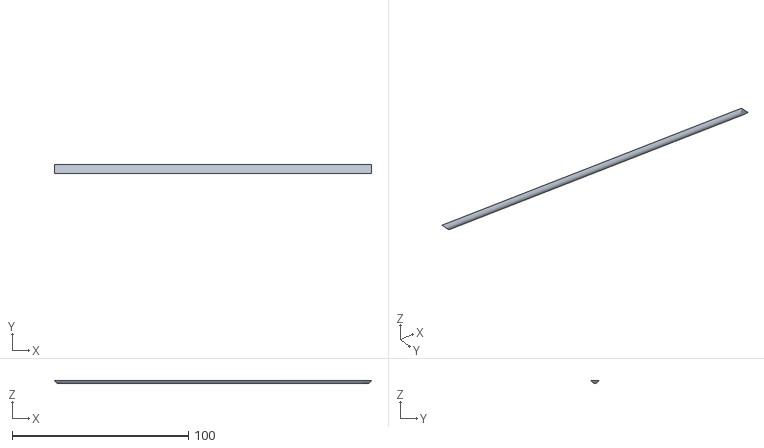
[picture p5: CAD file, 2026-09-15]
model_v2/Body9.stl
180.0 x 5.00 x 1.67

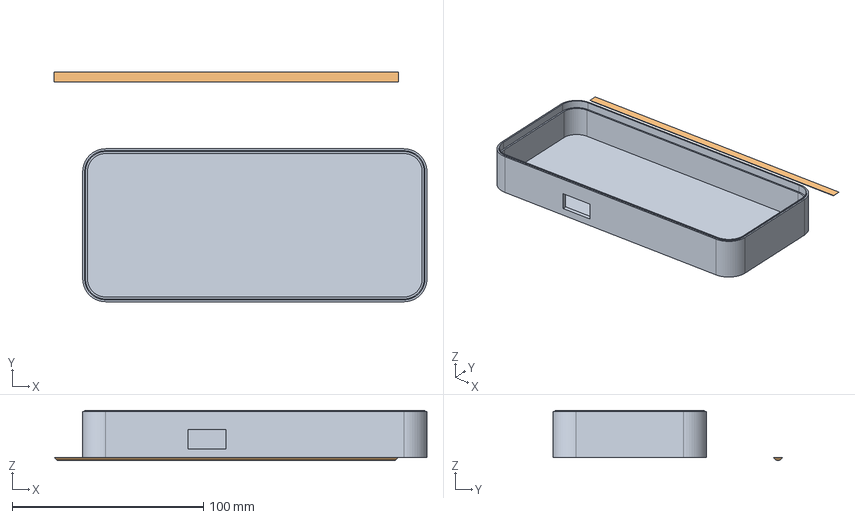
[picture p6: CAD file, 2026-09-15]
model_v2/STEP/FINAL BRAILLE BOTTOM.step
195.0 x 120.0 x 26.2 mm

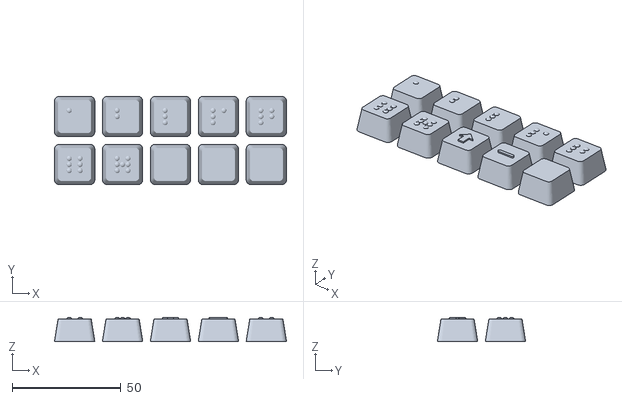
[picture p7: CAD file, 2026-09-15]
models/KEYCAPS_FINAL.stl
106.5 x 40.5 x 11.2

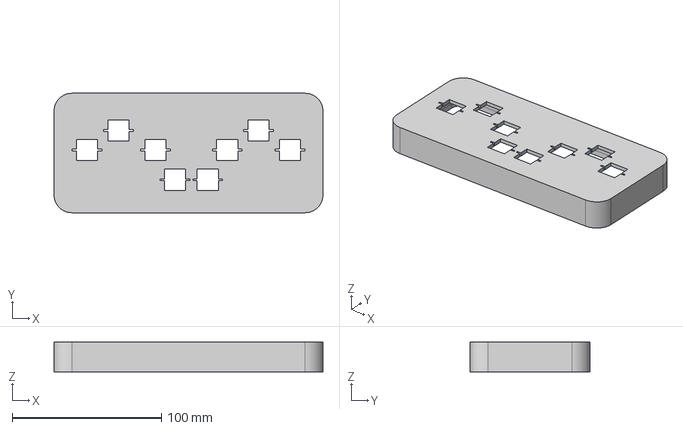
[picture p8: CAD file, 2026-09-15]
model_v2/STEP/FINAL BRAILLE TOP.step
180.0 x 80.0 x 20.0 mm

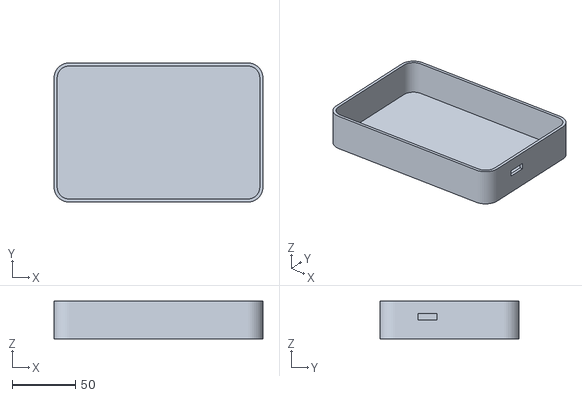
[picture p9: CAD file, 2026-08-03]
models/BOTTOM_SHELL.stl
165.0 x 110.0 x 30.0

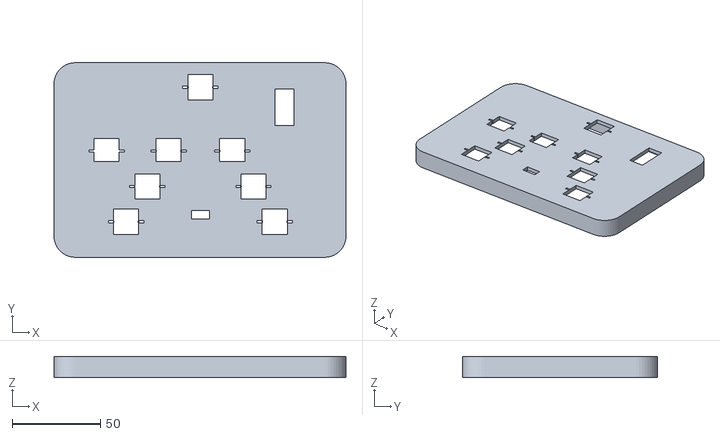
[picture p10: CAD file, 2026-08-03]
models/TOP_SHELL.stl
165.0 x 110.0 x 12.0

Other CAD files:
model_v2/FINAL BRAILLE BOTTOM.3mf
model_v2/FINAL BRAILLE BOTTOM.stl
model_v2/FINAL BRAILLE TOP.3mf
model_v2/FINAL BRAILLE TOP.stl

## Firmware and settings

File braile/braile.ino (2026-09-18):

#include <Arduino.h>
#include "BBKeyboard.h"

// ==========================================
// BrailleBridge — ESP32 firmware
//
// BLE exposes TWO services at once:
//   1. HID keyboard (0x1812)  → typed characters reach any paired
//      computer/phone text field exactly like the original T-vK
//      BleKeyboard build (phone keyboard mode works again).
//   2. Nordic UART Service    → the raw character + control-line stream
//      (the same bytes that go to USB Serial) mirrored over BLE so the
//      phone app (see PHONE.md) receives it without a USB cable.
//
// HID layer (v4): back on the PROVEN T-vK BleKeyboard code — vendored as
// BBKeyboard (braile/BBKeyboard.h/.cpp) so the sketch needs no library
// install. Its GATT layout, pairing mode, report map and advertising are
// byte-for-byte the library build that worked on phones and PCs in v1;
// only the Nordic UART Service was grafted on for the phone app.
// (History: the v2/v3 hand-rolled GATT rewrite broke typing everywhere —
// malformed report-map Report-ID item — and later broke discoverability
// via an overflowing advertising payload. Both are gone with the rewrite.)
// ==========================================

// ==========================================
// PIN DEFINITIONS
// ==========================================
#define DOT_1 14
#define DOT_2 12
#define DOT_3 13
#define DOT_4 27
#define DOT_5 26
#define DOT_6 25
#define SPACE 33
#define SHIFT 32
// (Physical Shift button — hold while pressing dots for uppercase/numbers/math/Bangla vowel signs)
// Tap Shift alone (press + release without any chord) → Backspace (deletes last character)
// #define RED_LED 18
// #define GREEN_LED 19

// ==========================================
// BRAILLE ENTRY STRUCTURE
// ==========================================
struct BrailleEntry {
  uint8_t chord;
  const char* english;
  const char* bangla;
};

// ==========================================
// BRAILLE DICTIONARY — Bharati Braille Standard
// ==========================================
// Based on the Bharati Braille standard (https://en.wikipedia.org/wiki/Bharati_Braille)
// Dot patterns follow International Phonetic Alphabet (IPA) mappings.
//
const BrailleEntry brailleDict[] = {
// ===== Shared English + Bangla chords (Bharati standard) =====
{ 0b000001, "a", "অ" },     // dot 1 = অ
{ 0b000011, "b", "ব" },     // dots 12 = ব
{ 0b001001, "c", "চ" },     // dots 14 = চ
{ 0b011001, "d", "দ" },     // dots 145 = দ
{ 0b010001, "e", "এ" },     // dots 15 = এ
{ 0b001011, "f", nullptr },  // dots 124 = (no standard Bharati Bengali)
{ 0b011011, "g", "গ" },     // dots 1245 = গ
{ 0b010011, "h", "হ" },     // dots 125 = হ
{ 0b001000, "i", "্" },     // dot 4 = হসন্ত (virama/halant)
{ 0b011010, "j", "জ" },     // dots 245 = জ
{ 0b000101, "k", "ক" },     // dots 13 = ক
{ 0b000111, "l", "ল" },     // dots 123 = ল
{ 0b001101, "m", "ম" },     // dots 134 = ম
{ 0b011101, "n", "ন" },     // dots 1345 = ন
{ 0b010101, "o", "ও" },     // dots 135 = ও
{ 0b001111, "p", "প" },     // dots 1234 = প
{ 0b011111, "q", "ক্ষ" },   // dots 12345 = ক্ষ
{ 0b010111, "r", "র" },     // dots 1235 = র
{ 0b001100, "s", "ঐ" },     // dots 34 = ঐ
{ 0b011100, "t", "আ" },     // dots 345 = আ
{ 0b100101, "u", "উ" },     // dots 136 = উ
{ 0b100111, "v", "ৱ" },     // dots 1236 = ৱ (Assamese/Bengali v)
{ 0b111010, "w", nullptr },  // dots 2456 = w
{ 0b101101, "x", "য" },     // dots 1346 = য (yya) — convenience
{ 0b111101, "y", "য" },     // dots 13456 = য
{ 0b110101, "z", "ড়" },     // dots 1356 = z + ড়

  // ===== Bangla-only chords (standard Bharati cells) =====
  { 0b001010, nullptr, "ই" },    // dots 24 = ই
  { 0b010010, nullptr, "ঞ" },    // dots 25 = ঞ
  { 0b001110, nullptr, "স" },    // dots 234 = স
  { 0b111111, nullptr, "ঢ" },    // all 6 dots = ঢ
  { 0b100001, nullptr, "ছ" },    // dots 16 = ছ
  { 0b100011, nullptr, "ঘ" },    // dots 126 = ঘ
  { 0b011000, nullptr, "ভ" },    // dots 45 = ভ (you said 245 but জ is already there, 45 per standard Bharati)
  { 0b111001, nullptr, "থ" },    // dots 1456 = থ
  { 0b110110, nullptr, "ঠ" },    // dots 2456 = ঠ
  { 0b101010, nullptr, "ঔ" },    // dots 246 = ঔ
  { 0b010110, nullptr, "ফ" },    // dots 235 = ফ
  { 0b110100, nullptr, "ঝ" },    // dots 356 = ঝ
  { 0b101011, nullptr, "ড" },    // dots 1246 = ড
  { 0b010100, nullptr, "ঈ" },    // dots 35 = ঈ

  // ===== Additional Bharati cells (not in original dict) =====
  { 0b011110, nullptr, "ত" },    // dots 2345 = ত
  { 0b101000, nullptr, "খ" },    // dots 46 = খ
  { 0b101100, nullptr, "ঙ" },    // dots 346 = ঙ
  { 0b111110, nullptr, "ট" },    // dots 23456 = ট
  { 0b101110, nullptr, "ধ" },    // dots 2346 = ধ
  { 0b111100, nullptr, "ণ" },    // dots 3456 = ণ
  { 0b110011, nullptr, "ঊ" },    // dots 1256 = ঊ
  { 0b101111, nullptr, "ষ" },    // dots 12346 = ষ
  { 0b110001, nullptr, "শ" },    // dots 156 = শ
  { 0b110000, nullptr, "ং" },    // dots 56 = অনুস্বার
  // ঃ (visarga) at dot 6 (0b100000) — available for future use
  { 0b010000, nullptr, "ঁ" },    // dot 5 = চন্দ্রবিন্দু

  // ===== Non-standard convenience chords =====
  { 0b100110, nullptr, "ি" },    // ই-কার (convenience, not a Bharati cell)
  { 0b110010, nullptr, "ূ" },    // দীর্ঘ উ-কার (convenience, not a Bharati cell)
  // ড় moved to shared section with z at 0b110101
  { 0b100010, nullptr, "স" },    // duplicate স at dots 236 (convenience)
};

// Number mappings for Shift + a-j
const char* numberMap[] = { "1", "2", "3", "4", "5", "6", "7", "8", "9", "0" };

// Chords for a-j (used for number lookup)
const uint8_t numberChords[] = {
  0b000001,  // a → 1
  0b000011,  // b → 2
  0b001001,  // c → 3
  0b011001,  // d → 4
  0b010001,  // e → 5
  0b001011,  // f → 6
  0b011011,  // g → 7
  0b010011,  // h → 8
  0b001000,  // i → 9
  0b011010,  // j → 0
};

// Shift symbols — math & punctuation via Shift + chord (language-independent)
// Note: some punctuation shares chord values with math; math entries come first in conflicts.
struct ShiftSymbol {
  uint8_t chord;
  const char* symbol;
};

const ShiftSymbol shiftSymbols[] = {
  // Math symbols
  { 0b010110, "+" },   // dots 235 = plus
  { 0b100100, "-" },   // dots 36  = minus
  { 0b100110, "×" },   // dots 236 = times
  { 0b110110, "=" },   // dots 2356 = equals
  { 0b001100, "÷" },   // dots 34  = divide

  // Punctuation & decimal
  { 0b000010, "," },   // dot 2   = comma
  { 0b000110, ";" },   // dots 23 = semicolon
  { 0b010010, ":" },   // dots 25 = colon
  { 0b110010, "." },   // dots 256 = decimal point / period
};

// Bangla vowel → vowel sign mapping (Shift + vowel → kar/matra)
struct BanglaShiftEntry {
  uint8_t chord;
  const char* kar; // vowel sign
};

const BanglaShiftEntry banglaShiftMap[] = {
  { 0b000001, nullptr },   // অ → (no sign)
  { 0b011100, "া" },       // আ → আ-কার  (Bharati: dots 345)
  { 0b001010, "ি" },       // ই → ই-কার  (Bharati: dots 24)
  { 0b010100, "ী" },       // ঈ → দীর্ঘ ই-কার (Bharati: dots 35)
  { 0b100101, "ু" },       // উ → উ-কার  (Bharati: dots 136)
  { 0b110011, "ূ" },       // ঊ → দীর্ঘ উ-কার (Bharati: dots 1256)
  { 0b010001, "ে" },       // এ → এ-কার  (Bharati: dots 15)
  { 0b001100, "ৈ" },       // ঐ → ঐ-কার  (Bharati: dots 34)
  { 0b010101, "ো" },       // ও → ও-কার  (Bharati: dots 135)
  { 0b101010, "ৌ" },       // ঔ → ঔ-কার  (Bharati: dots 246)
};

// ==========================================
// FORWARD DECLARATIONS (used by the BLE layer & loop)
// ==========================================
extern bool isBangla;
void sendChar(const char* c);
void sendBackspace();
void processChord(int chord);

// ==========================================
// BLE OBJECT — vendored T-vK library + NUS
// ==========================================
BBKeyboard bleKeyboard("BrailleBridge");   // T-vK BleKeyboard + NUS (see BBKeyboard.h)

// Stream a piece of text to BOTH outputs: USB Serial (teacher app) and
// BLE NUS (phone app). ASCII, Bangla and control lines all flow through here.
void streamOut(const char* s, bool newline) {
  Serial.print(s);
  if (newline) Serial.println();
  bleKeyboard.streamText(s, newline);
}

// Phone app → device control lines over NUS RX (same vocabulary as Serial).
void onNusControl(const String& value) {
  String v = value; v.trim();
  if (v == "LANG:en")      { isBangla = false; streamOut("LANG:en", true); }
  else if (v == "LANG:bn") { isBangla = true;  streamOut("LANG:bn", true); }
  else                     { streamOut("Invalid", true); }
}

// ==========================================
// OBJECTS & GLOBALS
// ==========================================
unsigned long pressStartTime = 0;
bool chordActive = false;
int currentChord = 0;
bool isBangla = false;
bool shiftActive = false;

// --- Shift tap → Backspace state machine ---
// Shift normally acts as a held modifier. If it is pressed AND released
// without any dot chord being composed meanwhile, that tap is a Backspace.
bool shiftWasDown = false;      // Shift was held at some point since last release
bool shiftTapUsed = false;      // a chord was processed (or Space) while Shift was held
unsigned long shiftDownTime = 0;  // when the current Shift press started
unsigned long lastBackspaceMs = 0;  // cooldown anchor so release bounce can't chain deletes
const unsigned long SHIFT_TAP_MAX_MS = 1500;  // ultra-long presses are not taps (pocket/garage protection)
const unsigned long SHIFT_TAP_MIN_MS = 25;    // shorter than this = press bounce, not a real tap
const unsigned long SHIFT_BKSP_COOLDOWN_MS = 100;  // ignore re-arms right after a fired delete

// ==========================================
// DICTIONARY LOOKUP
// ==========================================
const char* lookupChord(int chord, bool bangla) {
  for (unsigned int i = 0; i < sizeof(brailleDict) / sizeof(brailleDict[0]); i++) {
    if (brailleDict[i].chord == chord) {
      if (bangla && brailleDict[i].bangla != nullptr) return brailleDict[i].bangla;
      if (!bangla && brailleDict[i].english != nullptr) return brailleDict[i].english;
      return nullptr; // chord exists but not in this language
    }
  }
  return nullptr; // not found
}

// ==========================================
// SETUP
// ==========================================
void setup() {
  Serial.begin(115200);

  pinMode(DOT_1, INPUT_PULLUP);
  pinMode(DOT_2, INPUT_PULLUP);
  pinMode(DOT_3, INPUT_PULLUP);
  pinMode(DOT_4, INPUT_PULLUP);
  pinMode(DOT_5, INPUT_PULLUP);
  pinMode(DOT_6, INPUT_PULLUP);
  pinMode(SPACE, INPUT_PULLUP);
  pinMode(SHIFT, INPUT_PULLUP);

  // pinMode(RED_LED, OUTPUT);
  // pinMode(GREEN_LED, OUTPUT);
  // setEnglishLED(); // Start in English mode

  bleKeyboard.begin();
  bleKeyboard.setNusRxHandler(onNusControl);
  Serial.println("SYSTEM: BrailleBridge Connected. Waiting for BLE...");
}

// ==========================================
// MAIN LOOP
// ==========================================
void loop() {
  bleKeyboard.processEvents();   // handle connect/disconnect/NUS-RX events

  bool d1 = digitalRead(DOT_1) == LOW;
  bool d2 = digitalRead(DOT_2) == LOW;
  bool d3 = digitalRead(DOT_3) == LOW;
  bool d4 = digitalRead(DOT_4) == LOW;
  bool d5 = digitalRead(DOT_5) == LOW;
  bool d6 = digitalRead(DOT_6) == LOW;
  bool sp = digitalRead(SPACE) == LOW;
  bool sh = digitalRead(SHIFT) == LOW;

  // ----- SHIFT MODIFIER (held while pressed, like a real keyboard Shift) -----
  shiftActive = sh;  // sh is already true when pressed (digitalRead(...)==LOW)

  // ----- SHIFT TAP → BACKSPACE -----
  // Track Shift press/release edges. A clean tap (released quickly, with no
  // chord or Space used while it was held) deletes the last typed character.
  if (sh) {
    if (!shiftWasDown) {           // falling edge: Shift just went down
      shiftWasDown = true;
      // Cooldown: if a backspace just fired, this re-arm is bounce residue,
      // not a fresh tap — mark it used so its release can't fire again.
      shiftTapUsed = (millis() - lastBackspaceMs) < SHIFT_BKSP_COOLDOWN_MS;
      shiftDownTime = millis();
    }
  } else if (shiftWasDown) {       // rising edge: Shift just came back up
    shiftWasDown = false;
    bool dotsHeld = d1 || d2 || d3 || d4 || d5 || d6;
    // Fire only on a clean tap: quick, unused, and not in the middle of a chord
    unsigned long held = millis() - shiftDownTime;
    if (!shiftTapUsed && !dotsHeld && held >= SHIFT_TAP_MIN_MS && held <= SHIFT_TAP_MAX_MS) {
      sendBackspace();
      lastBackspaceMs = millis();
      delay(30);                 // swallow release bounce so it can't double-fire
    }
    shiftTapUsed = false;
  }

  // ----- SPACE -----
  if (sp && !d1 && !d2 && !d3 && !d4 && !d5 && !d6) {
    if (sh) shiftTapUsed = true;   // Shift was doing something while held
    sendChar(" ");
    delay(200);
    while (digitalRead(SPACE) == LOW) { delay(10); }
    return;
  }

  // ----- CHORD DETECTION -----
  bool anyDot = d1 || d2 || d3 || d4 || d5 || d6;

  if (anyDot) {
    if (shiftWasDown) shiftTapUsed = true;  // dots involved → this Shift is a modifier, not a tap
    if (!chordActive) {
      chordActive = true;
      pressStartTime = millis();
      currentChord = 0;
    }

    if (d1) currentChord |= (1 << 0);
    if (d2) currentChord |= (1 << 1);
    if (d3) currentChord |= (1 << 2);
    if (d4) currentChord |= (1 << 3);
    if (d5) currentChord |= (1 << 4);
    if (d6) currentChord |= (1 << 5);
  }

  if (chordActive) {
    unsigned long elapsed = millis() - pressStartTime;
    bool allReleased = !anyDot;

    // D4+D5+D6 held 500ms → language toggle
    if (currentChord == 0b111000 && elapsed >= 500 && !allReleased) {
      isBangla = !isBangla;
      streamOut(isBangla ? "LANG:bn" : "LANG:en", true);
      if (shiftActive) shiftTapUsed = true;  // Shift was part of a deliberate gesture, not a tap
      chordActive = false;
      currentChord = 0;

      // Wait for all three keys to be released
      while (digitalRead(DOT_4) == LOW || digitalRead(DOT_5) == LOW || digitalRead(DOT_6) == LOW) {
        delay(10);
      }
      delay(50);
      return;
    }

    // Process when all released or timeout (180ms)
    if (allReleased || elapsed > 180) {
      // If D4+D5+D6 is still held and < 500ms, keep waiting
      if (!allReleased && currentChord == 0b111000 && elapsed < 500) {
        // Wait longer for potential toggle
      } else {
        if (shiftActive) shiftTapUsed = true;  // chord consumed the Shift modifier
        processChord(currentChord);
        chordActive = false;
        currentChord = 0;
        delay(50);
      }
    }
  }
}

// ==========================================
// BACKSPACE — delete the last typed character
// ==========================================
void sendBackspace() {
  if (bleKeyboard.isConnected()) {
    bleKeyboard.press(KEY_BACKSPACE);
    delay(8);
    bleKeyboard.releaseAll();
  }
  streamOut("SYSTEM:BKSP", true);   // teacher app listens for this control line
}

// ==========================================
// SEND CHARACTER TO BLE & STREAM
// ==========================================
void sendChar(const char* c) {
  // HID keycodes can only represent ASCII. Bangla (multi-byte UTF-8) has no
  // keycode mapping, and pushing it through the HID stack can wedge the
  // ESP32 and cause a reboot. So:
  //   - ASCII  → HID keyboard (paired host types it out) + stream
  //   - Bangla → stream only (USB Serial + BLE NUS → teacher/phone app)
  bool isAscii = true;
  for (const char* p = c; *p; p++) {
    if ((unsigned char)*p >= 0x80) { isAscii = false; break; }
  }
  if (bleKeyboard.isConnected() && isAscii) {
    bleKeyboard.print(c);
  }
  // The stream carries EVERYTHING (ASCII + Bangla + control lines) — this is
  // what the teacher software and the phone app receive.
  streamOut(c, false);
}

// ==========================================
// PROCESS A BRAILLE CHORD
// ==========================================
void processChord(int chord) {
  // ----- SHIFTED CHORD (activated by physical SHIFT button) -----
  if (shiftActive) {
    // shiftActive follows the button state in loop(), so it resets naturally on release

    // Check for numbers (a-j chords → 1-0)
    for (int i = 0; i < 10; i++) {
      if (chord == numberChords[i]) {
        sendChar(numberMap[i]);
        // flashValid();
        return;
      }
    }

    // Check for shift symbols — math & punctuation (language-independent)
    for (unsigned int i = 0; i < sizeof(shiftSymbols) / sizeof(shiftSymbols[0]); i++) {
      if (chord == shiftSymbols[i].chord) {
        sendChar(shiftSymbols[i].symbol);
        // flashValid();
        return;
      }
    }

    // English uppercase
    if (!isBangla) {
      const char* ch = lookupChord(chord, false);
      if (ch != nullptr && ch[0] >= 'a' && ch[0] <= 'z') {
        char upper[2] = { (char)(ch[0] - 32), '\0' };
        sendChar(upper);
        // flashValid();
        return;
      }
    }
    // Bangla shifted: vowel → vowel sign (কার)
    else {
      // Check vowel sign map first
      for (unsigned int i = 0; i < sizeof(banglaShiftMap) / sizeof(banglaShiftMap[0]); i++) {
        if (banglaShiftMap[i].chord == chord) {
          if (banglaShiftMap[i].kar != nullptr) {
            sendChar(banglaShiftMap[i].kar);
            // flashValid();
            return;
          }
          // অ has no vowel sign → fall through to normal output
          break;
        }
      }

      // Not a vowel chord, or অ → output normal Bangla character
      const char* ch = lookupChord(chord, true);
      if (ch != nullptr) {
        sendChar(ch);
        // flashValid();
        return;
      }
    }

    // Unknown shifted chord → silently ignore
    // flashInvalid();
    // Serial.println("Invalid");
    return;
  }

  // ----- NORMAL (UNSHIFTED) CHORD -----
  const char* result = lookupChord(chord, isBangla);
  if (result != nullptr) {
    sendChar(result);
  }
  // Unknown chord → silently ignore
}

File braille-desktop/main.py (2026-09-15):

import json
import os

import webview

from relay import RelayManager

BASE_DIR = os.path.dirname(os.path.abspath(__file__))
INDEX_FILE = os.path.abspath(os.path.join(BASE_DIR, '..', 'braille-display', 'index.html'))


class BridgeApi:

    def __init__(self):
        self._window = None
        self._relay = None

    def attach(self, window):
        self._window = window

        def emit(kind, port, payload):
            try:
                if kind == 'data':
                    code = f'window.__relayOnData({json.dumps(port)}, {json.dumps(payload)})'
                elif kind == 'ports':
                    code = f'window.__relayOnPorts({json.dumps(payload)})'
                else:
                    code = f'window.__relayOnEvent({json.dumps(port)}, {json.dumps(kind)})'
                window.evaluate_js(code)
            except Exception:
                pass  # UI not ready yet — the relay keeps buffering

        self._relay = RelayManager(emit)

    # ------------------------------------------------------------ js_api
    def list_ports(self):
        return self._relay.list_ports()

    def open_port(self, port_name, baud=115200):
        return self._relay.open_port(port_name, int(baud))

    def close_port(self, port_name):
        return self._relay.close_port(port_name)

    def get_assignments(self):
        return self._relay.get_assignments()

    def set_assignment(self, name, port_name):
        return self._relay.set_assignment(name, port_name)

    def save_all_logs(self):
        saved = self._relay.save_all_logs()
        return f'Saved {saved} session log(s) to the logs/ folder.'

    # ------------------------------------------------------------ cleanup
    def shutdown(self):
        if self._relay:
            self._relay.save_all_logs()
            self._relay.shutdown()


def main():
    api = BridgeApi()
    index_url = 'file:///' + INDEX_FILE.replace('\\', '/')
    window = webview.create_window(
        'BrailleBridge — Teacher Desktop',
        url=index_url,
        js_api=api,
        width=1440,
        height=920,
        min_size=(1100, 700),
    )
    api.attach(window)
    window.events.closing += api.shutdown
    webview.start(debug=False)


if __name__ == '__main__':
    main()

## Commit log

2026-08-03 Initial Commit(2)
    [BOTTOM_SHELL.stl, TOP_SHELL.stl]
2026-09-15 Adding thingz
    [Body9.stl, FINAL BRAILLE BOTTOM.3mf, FINAL BRAILLE BOTTOM.step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]
2026-11-02 fix(android): multi-device BLE, Bangla TTS fallback, control line filtering, unit test suite & CI verification
2026-11-04 fix(ui): resolve global header/nav flaws, button clipping, and screen layout defects across student, teacher, exam, and learn views
2026-11-04 fix(ui): standardize 10dp button corner radii, prevent font scaling truncation, and refine header & nav styling
2026-11-13 Remove all AI emojis, add crisp SVG vector icon engine for PyQt6 desktop and Material icons on Android
2026-11-13 Fix Light mode scroll areas & combo popups, add typing animations & Student View Sound ON/OFF button
2026-11-13 style(desktop): switch typography to SF Pro Display and polish indicator/log card borders
2026-11-13 fix(desktop): tighten Teacher feed card header spacing and max height
2026-11-13 fix(desktop): pin 6-Dot Braille Cell header to top and center dot grid cleanly
